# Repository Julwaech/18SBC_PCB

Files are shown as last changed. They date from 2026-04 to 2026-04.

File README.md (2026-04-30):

# 18SBC PCB

18-Series Battery Connector Board — a high-current PCB designed for 18S lithium battery pack integration in heavy-lift UAV systems.

## Overview

The 18SBC is a battery connector board that interfaces 18S smart battery packs (e.g. Tattu 4.0) with the aircraft electrical system.

### Design Goals

- Support 18S smart batteries (Tattu 4.0 compatible)
- Handle 100A continuous / 200A spike current
- Provide galvanically isolated 12V output (GNDE) to the aircraft power distribution board
- Provide non-isolated 5V / 3.3V (GNDI) for onboard logic (ESP32, CAN, diagnostics)
- Active power switching with precharge and emergency shutoff
- Dual CAN bus communication (battery protocol + DroneCAN)
- Wireless connectivity (WiFi / BLE) for diagnostics and configuration
- USB-C interface for debugging, firmware flashing, and development

## Board Overview (Fusion 360 Renders)

> **Note:** These renders are for visualization purposes — the ESP32-S3, MCP2515, and other small ICs are not yet modeled in the CAD. The renders show the physical layout of the major connectors, fuse, and power path components.

### Render 1 — Board Inserted in 18S Tattu Battery

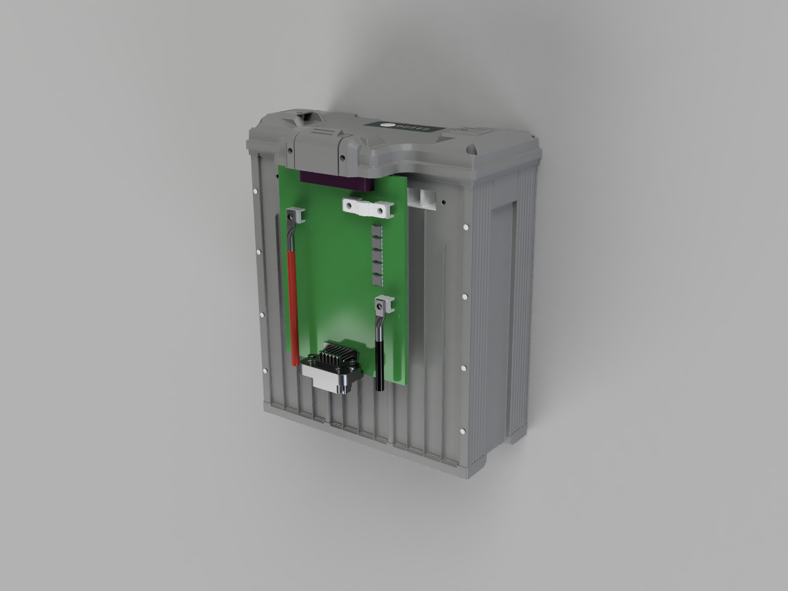
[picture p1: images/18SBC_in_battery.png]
18SBC in Tattu Battery


The board is shown inserted vertically into an 18S Tattu 4.0 smart battery pack to illustrate how the battery connector (purple, top) mates with the battery's interface.

**Visible components (top to bottom):**

| Position | Component | Description |
|---|---|---|
| Top | **AMT0650009DB0000G** screw terminals + **DB128V-5.08-4P-GN-S** signal terminal | Battery interface — power (+ / -) and CAN L/H + interlock signals. Layout: Positive (left) \| Signal (center) \| Negative (right) |
| Upper right | **White ceramic component** (AMXL-250) | 250A main fuse, bolt-mounted on 2x AMT0650009DB0000G screw terminals |
| Below fuse | **MOSFETs** | Power switching (precharge, kill switch, power enable) |
| Below MOSFETs | **Black cable** with ring lug | Negative output to Hobbywing X15 propulsion, connected via AMT0650009DB0000G screw terminal |
| Middle left | **Red cable** with ring lug | Positive output to Hobbywing X15 propulsion, connected via AMT0650009DB0000G screw terminal |
| Bottom | **AT13-12PB-BM03** signal connector | 12-position Amphenol AT series — interfaces with the drone electrical harness (12V, 5V, GND, CAN, signals) |

### Render 2 — Board Front View

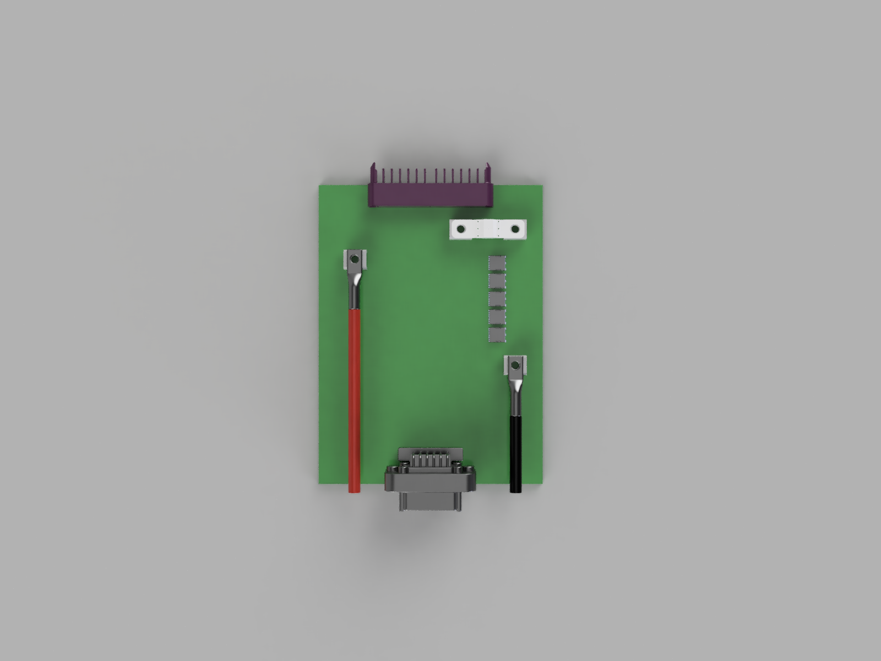
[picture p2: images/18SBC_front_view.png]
18SBC Front View


Frontal view of the PCB showing component placement and general board layout. The power path flows from the battery connector (top) through the fuse and MOSFETs to the propulsion screw terminals (red/black cables). The signal connector exits at the bottom toward the drone harness.

### Signal Flow

```
Battery (18S Tattu 4.0)
        |
        v
+---------------------+
|  Battery Terminals   |  <- Power (+ / -) via AMT0650009DB0000G
|  + Signal Terminal   |  <- CAN L/H + Interlock via DB128V-5.08-4P
+---------------------+
|  AMXL-250 Fuse       |  <- 250A short-circuit protection
+---------------------+
|  MOSFETs             |  <- Precharge / Kill switch / Power enable
+---------------------+
|  Screw Terminals     |  <- Red (+) and Black (-) cables
|  (AMT0650009DB0000G) |     to Hobbywing X15 propulsion
+---------------------+
|                       |
|  HV Bus (54-75.6V)   |
|    |            |     |
|    v            v     |
|  [Buck]    [Push-Pull]|
|  5V/1A     12V/10A   |
|  (GNDI)    (isolated) |
|    |        (GNDE)    |
|    v            |     |
|  [LDO]         |     |
|  3.3V          |     |
|  (GNDI)        |     |
+---------------------+
|  AT Signal Connector |  <- 12V (GNDE), DroneCAN, signals
|  (AT13-12PB-BM03)   |     to aircraft harness
+---------------------+
```

## Specifications

| Parameter | Value |
|---|---|
| Configuration | 18S (18 series cell groups) |
| Max Voltage | 75.6V (4.2V x 18) |
| Nominal Voltage | 64.8V (3.6V x 18) |
| Continuous Current | 100A |
| Spike Current | 200A (short duration) |
| Board Shape | Rectangular |
| EDA Tool | KiCad 10 |
| Board Layers | TBD |

### Current Rating Justification

Based on the motor data (Hobbywing XRotor X15):

| Throttle | Thrust | Current per Motor |
|---|---|---|
| 51% | 27,257 g | 44.7 A |
| 72% | 47,933 g | 101.6 A |
| 100% | 72,647 g | 197.1 A |

The Hover throttle is ~50%. The 100A nominal rating covers normal operations; the 200A spike rating handles full-throttle bursts.

## Connectors and Fuse

### Battery Connector

#### Mating Connector (Battery Side): ACES 59604-0169D-003

This is the connector built into the Tattu 4.0 battery pack. The Prolanv EN60A on the 18SBC mates with this connector.

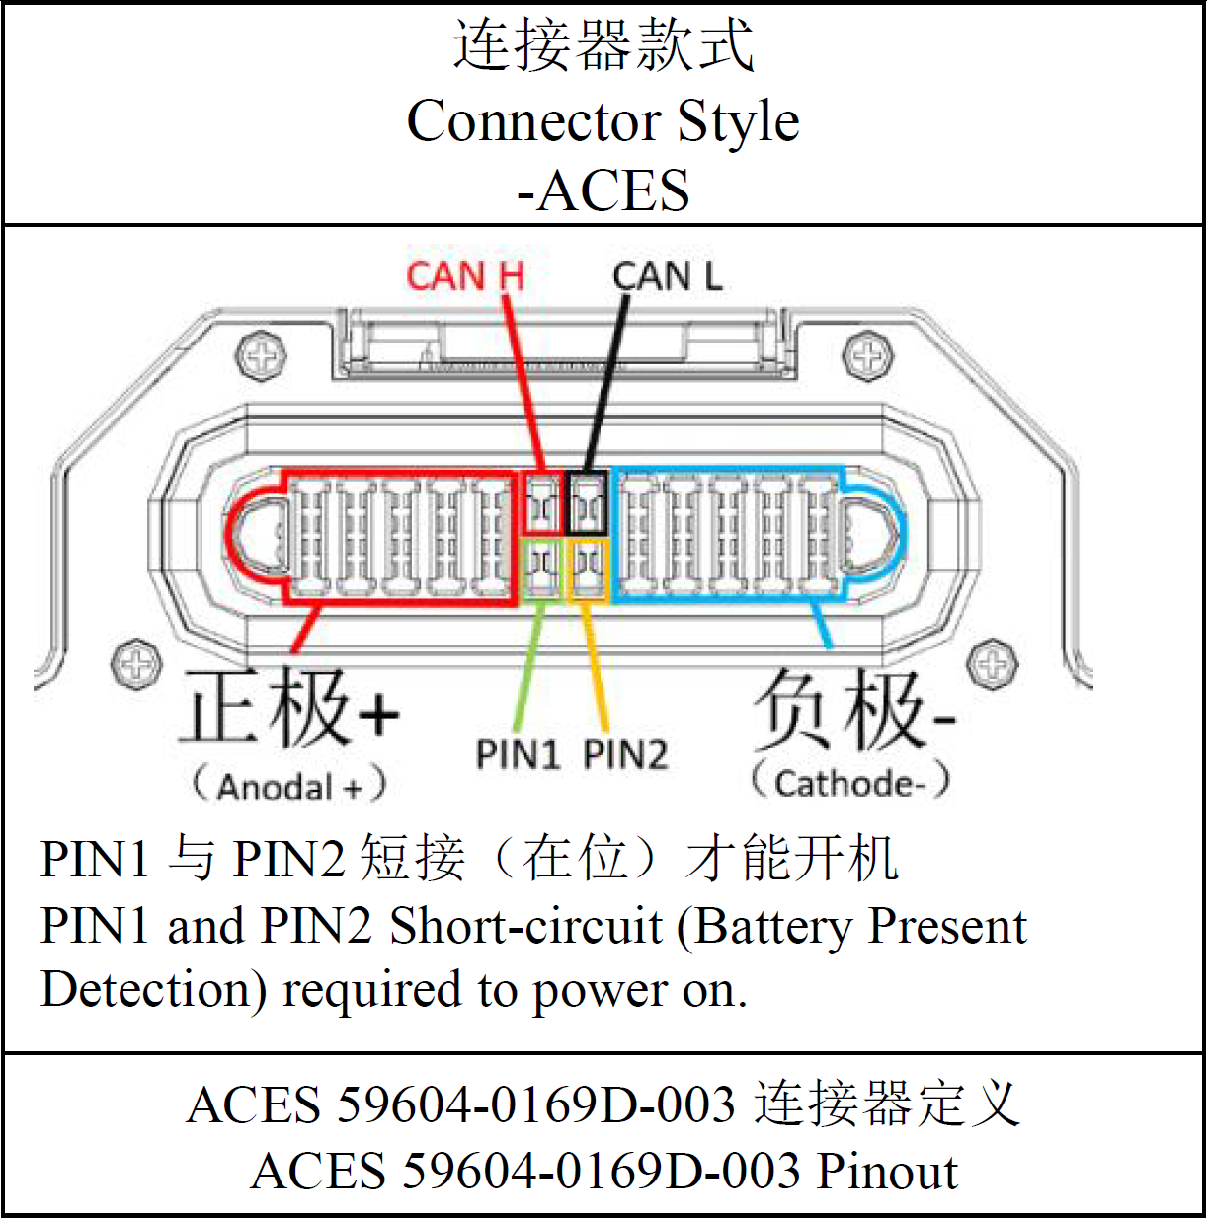
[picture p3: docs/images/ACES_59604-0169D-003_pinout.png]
ACES 59604-0169D-003 Pinout


| Position | Function | Notes |
|---|---|---|
| Left bank (red) | Anodal + (Positive) | Multiple parallel power contacts |
| Right bank (blue) | Cathode - (Negative) | Multiple parallel power contacts |
| Center top | CAN H + CAN L | Battery communication bus |
| PIN1 + PIN2 (center bottom) | Battery Present Detection | Must be shorted (bridged) for the battery to power on |

> **Important:** PIN1 and PIN2 must be short-circuited by the mating connector (Prolanv EN60A) to signal "battery present" — the battery will not power on without this bridge. The 18SBC must include a trace or jumper connecting these two pins on the EN60A side.

#### Board-Side Connectors: AMT0650009DB0000G (Power) + DB128V-5.08-4P-GN-S (Signal)

The original Prolanv EN60A connector was replaced due to mechanical fit issues. The battery interface now uses separate power and signal connectors:

**Power Terminals: [Amphenol Anytek AMT0650009DB0000G](https://www.mouser.com/ProductDetail/Amphenol-Anytek/AMT0650009DB0000G)**

Two screw terminals for positive and negative battery connections, same as used for propulsion output and fuse mounting.

| Parameter | Value |
|---|---|
| Type | Screw Terminal, Power Tap |
| Screw Size | M5 |
| Current Rating | 180A per terminal |
| Mounting | Through-Hole DIP |

**Signal Terminal: [DB128V-5.08-4P-GN-S](https://www.lcsc.com/product-detail/C2915641.html) (4-pin screw terminal block)**

| Parameter | Value |
|---|---|
| Type | 4-position screw terminal block |
| Pitch | 5.08mm |
| Pins | 4 (CAN H, CAN L, Interlock Pin1, Interlock Pin2) |
| LCSC | C2915641 |

**PCB Layout (top of board, left to right):**
- Positive terminal (AMT0650009DB0000G) — left
- Signal terminal (DB128V-5.08-4P-GN-S) — center
- Negative terminal (AMT0650009DB0000G) — right

> **Hardware Interlock:** Pin1 and Pin2 on the signal terminal must be bridged on the PCB. This signals "battery present" to the battery pack — the battery will not power on without this connection.

### Propulsion Screw Terminals

**Selected: [Amphenol Anytek AMT0650009DB0000G](https://www.mouser.com/ProductDetail/Amphenol-Anytek/AMT0650009DB0000G)**

These are the high-current screw terminals where cables to the Hobbywing X15 propulsion system are connected (+ and -).

| Parameter | Value |
|---|---|
| Type | Screw Terminal, Power Tap |
| Screw Size | M5 |
| Pins | 6 |
| Current Rating | 180A |
| Mounting | Through-Hole DIP |
| Contact Material | Brass + Steel Nut (matte tin plated) |
| Torque | 18 lbf·in |

Two sets of AMT0650009DB0000G screw terminals are used on the board: one pair for the propulsion output (+ / -), and another pair for mounting the main fuse (see below).

### Signal Connector (Drone Interface)

**Selected: [Amphenol AT13-12PB-BM03](https://www.amphenol-sine.com/AT13-12PB-BM03-12-Position-Right-Angle-Flange-Mount-PCB-Receptacle-Black-Tin-Plated-Contacts-Included-Keyed-B-Comparable-to-PN-DT13-12P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) (or similar AT series)**

This connector interfaces the 18SBC with the rest of the drone's electrical system (signal lines, regulated power outputs, CAN buses).

| Parameter | Value |
|---|---|
| Series | Amphenol AT (automotive-grade) |
| Type | Right-Angle Flange Mount PCB Receptacle |
| Positions | 12 |
| Keying | B |
| Contact Plating | Tin |
| Mating Connector | AT series cable plug (wire-to-board) |

The AT series is an automotive/industrial-grade connector family designed for harsh environments — vibration-resistant, sealed, and rated for high mating cycles. The 12 positions carry the isolated 12V output (GNDE), CAN bus lines, and control signals.

### USB-C Connector (Debug / Programming)

A USB-C connector is provided for firmware flashing, serial debugging, and development. It connects to the ESP32-S3's native USB interface (GPIO19 = D-, GPIO20 = D+).

| Parameter | Value |
|---|---|
| Type | USB-C receptacle |
| Interface | USB 2.0 (native ESP32-S3 USB) |
| Purpose | Firmware flashing, serial monitor, debugging |
| Power | Not used for board power (debug only) |
### Main Fuse (Short-Circuit Protection)

**Selected: [Eaton AMXL-250](https://www.eaton.com/content/dam/eaton/products/electronic-components/resources/data-sheet/eaton-amx-amxl-automotive-bolt-in-fuse-data-sheet-elx1218-en.pdf)**

The main fuse sits between the battery connector and the power output stage, protecting against short circuits. It is mounted on two AMT0650009DB0000G screw terminals (bolt-in design).

| Parameter | Value |
|---|---|
| Type | Automotive bolt-in fuse |
| Current Rating | 250A |
| Voltage Rating | 125 Vdc |
| Body | Ceramic |
| Mounting | Bolt-in (M5 terminals) on 2x AMT0650009DB0000G |

The 250A fuse rating provides short-circuit protection while allowing the full 200A spike current without nuisance blowing. The ceramic body handles the thermal demands of high-current interruption.

## MCU and Communication

### MCU: ESP32-S3-WROOM-1-N16R8

The ESP32-S3-WROOM-1-N16R8 module is a compact RISC-V based microcontroller with integrated wireless connectivity. It includes a PCB antenna — no external antenna components are required. A keepout zone must be maintained around the antenna area on the PCB layout (no copper / ground plane underneath).

| Parameter | Value |
|---|---|
| Core | Dual-core Xtensa LX7, 240 MHz |
| Flash | 16 MB (external quad SPI) |
| SRAM | 512 KB |
| WiFi | 802.11 b/g/n (2.4 GHz) |
| Bluetooth | BLE 5.0 |
| GPIOs | 45 |
| SPI | 3x (1 used for dual MCP2515) |
| ADC | 20 channels, 12-bit |
| Operating Voltage | 3.0 – 3.6V |
| Deep Sleep Current | 7 uA |
| Antenna | Integrated PCB antenna |

### Dual CAN Bus (2x MCP2515 + Transceiver)

Two independent CAN networks using external MCP2515 controllers on a shared SPI bus. This provides identical timing behavior on both buses and clean separation of the battery-side and drone-side CAN domains.

| CAN Bus | Purpose | Controller | Transceiver |
|---|---|---|---|
| CAN 1 — Battery | Battery protocol (smart battery communication) | MCP2515 (SPI, CS1) | SN65HVD230 (3.3V) |
| CAN 2 — Drone | DroneCAN (UAVCAN v0) interface to aircraft | MCP2515 (SPI, CS2) | SN65HVD230 (3.3V) |

Each MCP2515 requires an 8 MHz crystal + 2x 22pF load capacitors. 120 Ohm termination resistors are optional (directly connected or selectable via solder jumper depending on bus topology).

The board converts between the battery protocol (CAN 1) and DroneCAN (CAN 2) using [libcanard](https://github.com/dronecan/libcanard).

### GPIO Allocation

| Function | GPIOs | Notes |
|---|---|---|
| SPI Bus (shared) — SCK, MOSI, MISO | 3 | Directly routed to both MCP2515 |
| MCP2515 #1 — CS1, INT1 | 2 | CAN 1 (Battery) |
| MCP2515 #2 — CS2, INT2 | 2 | CAN 2 (Drone) |
| Temperature Sensors | 2 | 1-Wire (e.g. DS18B20) or analog NTC via ADC |
| Circuit Switching | 4 | MOSFET gate drive (e.g. precharge, kill switch, power enable) |
| USB (D+ / D-) | 2 | Native USB for debugging/flashing |
| **Total Used** | **15** | |
| **Remaining / Reserve** | **30** | Available for future expansion |

Pin count provides comfortable headroom for all current functions with 9 GPIOs in reserve.

## Functional Requirements

### Power Path
- **High-side MOSFET switching** — N-channel MOSFETs with charge pump gate drive
- **Precharge circuit** — soft-start via resistor + relay/MOSFET to limit inrush current
- **Emergency kill switch** — hardware-level kill input, independent of MCU
- **Main fuse** — Eaton AMXL-250 (250A) bolt-in fuse for short-circuit protection

### Voltage Regulation

The power supply architecture uses two independent stages with full galvanic isolation between internal onboard logic (GNDI) and external drone systems (GNDE).

#### Internal Supply (GNDI — non-isolated)

Provides power for onboard logic (ESP32, MCP2515, CAN transceivers, gate drivers, sensors).

| Stage | Topology | IC | Input | Output | Notes |
|---|---|---|---|---|---|
| 5V Rail | Sync Buck | e.g. MP9487 or similar (100V+, integrated FETs, ≥1A) | 54–75.6V (HV Bus) | 5V / 1A | Main internal rail |
| 3.3V Rail | LDO | e.g. AMS1117-3.3 or similar | 5V | 3.3V | ESP32, MCP2515, CAN transceivers |

#### External Supply (GNDE — galvanically isolated)

Provides 12V to the aircraft power distribution board. Full galvanic isolation ensures no ground loops between the 6 battery packs in the aircraft, and prevents EMI/noise from the propulsion system reaching sensitive avionics.

| Stage | Topology | IC | Input | Output | Notes |
|---|---|---|---|---|---|
| Isolated 12V | Push-Pull | e.g. TI LM5030 or similar push-pull controller | 54–75.6V (HV Bus) | 12V / 10A (isolated) | 1:N transformer, GNDI ↔ GNDE fully isolated |

> **Isolation rationale:** The aircraft uses 6 independent battery packs, each with its own 18SBC. All 6 isolated 12V outputs are combined on a central power distribution board. Without isolation, all battery GNDs would be connected through the shared 12V/5V rails — creating ground loops and coupling propulsion noise into avionics. Galvanic isolation on each 18SBC prevents this.

### Monitoring and Communication
- **Dual CAN bus** — see [MCU and Communication](#mcu-and-communication) section above
- **Temperature sensors** — 2 pins reserved for monitoring battery connector and MOSFET hotspots (1-Wire or NTC/ADC)
- **WiFi / BLE** — integrated in ESP32-S3 for wireless diagnostics, configuration, and telemetry

### Protection
- **Short circuit protection** — Eaton AMXL-250 bolt-in fuse (250A, 125Vdc) mounted on dedicated screw terminals

## Repository Structure

```
18SBC_PCB/
├── README.md
├── kicad/              # KiCad 10 project files
│   ├── 18SBC.kicad_pro
│   ├── 18SBC.kicad_sch
│   └── 18SBC.kicad_pcb
├── docs/               # Documentation and datasheets
├── manufacturing/      # Gerber files and BOM
├── firmware/           # ESP32-S3 firmware (ESP-IDF / Arduino)
└── images/             # Board renders and photos
```

## Deliverables

1. **Schematic** — complete KiCad schematic with all subsystems
2. **PCB Layout** — rectangular board, routed for high current, antenna keepout zone respected
3. **BOM** — full bill of materials with supplier links
4. **Gerber files** — manufacturing-ready output for JLCPCB
5. **Documentation** — kicad files with component/footprint libraries in a zip folder.

## Getting Started

1. Install [KiCad 10](https://www.kicad.org/)
2. Clone this repository
3. Open `kicad/18SBC.kicad_pro`

## Reference Links

- [ESP32-S3-WROOM-1-N16R8 Datasheet](https://www.espressif.com/sites/default/files/documentation/esp32-s3-wroom-1-n16r8_datasheet_en.pdf) — MCU module
- [MCP2515 Datasheet](https://ww1.microchip.com/downloads/en/DeviceDoc/MCP2515-Stand-Alone-CAN-Controller-with-SPI-20001801J.pdf) — CAN controller
- [SN65HVD230 Datasheet](https://www.ti.com/lit/ds/symlink/sn65hvd230.pdf) — 3.3V CAN transceiver
- [AMT0650009DB0000G (Mouser)](https://www.mouser.com/ProductDetail/Amphenol-Anytek/AMT0650009DB0000G) — 180A screw terminal (propulsion + fuse mount)
- [AT13-12PB-BM03 (Amphenol)](https://www.amphenol-sine.com/AT13-12PB-BM03-12-Position-Right-Angle-Flange-Mount-PCB-Receptacle-Black-Tin-Plated-Contacts-Included-Keyed-B-Comparable-to-PN-DT13-12P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) — 12-pos signal connector
- [Eaton AMXL-250 Datasheet (PDF)](https://www.eaton.com/content/dam/eaton/products/electronic-components/resources/data-sheet/eaton-amx-amxl-automotive-bolt-in-fuse-data-sheet-elx1218-en.pdf) — 250A bolt-in fuse
- [DroneCAN](https://dronecan.github.io/) — CAN protocol for UAVs
- [libcanard](https://github.com/dronecan/libcanard) — lightweight DroneCAN implementation in C
- [DB128V-5.08-4P-GN-S (LCSC)](https://www.lcsc.com/product-detail/C2915641.html) — 4-pin screw terminal block (battery signal connector)
- [ESP32-S3-WROOM-1-N16R8 (LCSC)](https://www.lcsc.com/product-detail/C2913202.html) — MCU module (LCSC sourcing)

## License

TBD

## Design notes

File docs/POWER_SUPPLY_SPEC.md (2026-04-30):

# Power Supply Specification

## Overview

The 18SBC includes two independent step-down voltage regulators to provide power to external systems (flight controller, peripherals, sensors). These regulators are part of the **External GND Domain** and are galvanically separated from the internal board logic.

## Input

| Parameter | Value |
|---|---|
| Source | 18S HV Battery Bus |
| Voltage Range | 54.0V - 75.6V (3.0V - 4.2V per cell) |
| Component Rating | 100V DC |
| TVS Protection | 85V |

## Regulators

### Regulator 1 - 5V Rail

| Parameter | Value |
|---|---|
| Output Voltage | 5V (+-1.5%) |
| Continuous Current | 3-5A |
| Topology | Synchronous Buck |
| Efficiency | 90-96% typical |
| Output Ripple | <=35mV at full load |
| Protections | Overcurrent (self-recovery), thermal cutoff (150C), short-circuit tolerant |

### Regulator 2 - 12V Rail

| Parameter | Value |
|---|---|
| Output Voltage | 12V (+-1.5%) |
| Continuous Current | 3-5A |
| Topology | Synchronous Buck |
| Efficiency | 90-96% typical |
| Output Ripple | <=60mV at full load |
| Protections | Overcurrent (self-recovery), thermal cutoff (150C), short-circuit tolerant |

## Ground Domain Architecture

The 18SBC has two electrically separated ground domains:

### Internal GND (GNDI)
- ESP32-S3 MCU
- BMS logic
- MOSFET gate drivers
- Cell voltage sensing
- All internal signal processing

### External GND (GNDE)
- 5V and 12V regulator outputs
- Kill signal input (see [Kill Switch Spec](KILL_SWITCH_SPEC.md))
- All external connectors / interfaces

### Isolation Boundary

Signals crossing from External to Internal domain (or vice versa) **must be isolated**. Acceptable methods:
- Optocouplers
- Isolated gate drivers
- Isolated DC/DC converters

> **Rule:** DCDC regulator outputs may only be used internally if the signal path includes galvanic isolation before reaching the Internal GND domain.

## Battery Voltage Sensing

| Parameter | Value |
|---|---|
| Voltage Divider | 1k : 25k (input : ground) |
| Output | 0-2.91V for 0-75.6V input |
| Interface | 3.3V ADC compatible |
| Domain | Internal GND |

## Internal Power Supply

> **TBD** - The power source for the internal domain (ESP32-S3, BMS logic, etc.) is yet to be defined. Options under consideration include a dedicated isolated DC/DC converter from the HV bus or an isolated tap from one of the external regulators.

## Integration Notes

- The **Kill Switch** ([spec](KILL_SWITCH_SPEC.md)) operates on the External GND domain (12V rail). The kill signal crosses into the Internal domain via an optocoupler to reach the hardware AND-gate that controls the MOSFET enable line.
- External connectors must clearly indicate which ground domain they reference (GNDE).

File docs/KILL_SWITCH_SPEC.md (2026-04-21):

# 18SBC Emergency Kill Switch Specification

## Overview
The 18SBC receives a **12V emergency kill signal** from the Flight Controller (FC) via a dedicated cable. This signal must be hardware-debounced and capable of overriding the ESP32 MOSFET control to cut battery power.

## Signal Input
- **Voltage:** 12V (amplified from FC GPIO on a separate board)
- **Active State:** HIGH = Kill requested
- **Connector:** TBD (dedicated pin on signal connector)

## Hardware Debounce (1s minimum)
To prevent false cutoffs during flight (which would cause a crash), the kill signal must be stable for **>=1 second** before triggering.

### Implementation: RC Filter + Schmitt-Trigger
- **R = 150k ohm, C = 10uF** -> tau = 1.5s
- **Schmitt-Trigger** (e.g. 74LVC1G17, 3.3V logic):
  - Voltage divider before Schmitt-Trigger to scale 12V -> 3.3V range
  - Triggers at ~70% of input -> effective delay approx 1.05s
- Short spikes and EMI noise are fully absorbed by the RC filter

**Output:** KILL_CONFIRMED -- HIGH only after >=1s stable kill signal

## MOSFET Control Logic (Hardware AND-Gate)
The MOSFETs are controlled by a **hardware AND-gate** (e.g. 74LVC1G08) that combines the ESP32 enable signal with the inverted kill signal:

```
MOSFET_ENABLE = ESP32_ENABLE AND (NOT KILL_CONFIRMED)
```

### Truth Table
| ESP32_ENABLE | KILL_CONFIRMED | MOSFETs | State |
|---|---|---|---|
| LOW | LOW | **OFF** | Boot / Error |
| HIGH | LOW | **ON**  | Normal Operation |
| HIGH | HIGH | **OFF** | Emergency Kill |
| LOW | HIGH | **OFF** | Kill + No Enable |

### Key Properties
- **Default state is OFF** -- safe during boot, reset, or ESP32 failure
- **Hardware override** -- ESP32 cannot block or bypass the kill signal
- **ESP32 enable is active-high** -- must be explicitly driven HIGH for MOSFETs to turn on
- The AND-gate operates purely in hardware, independent of any firmware

## Component Summary
| Component | Part (Example) | Function |
|---|---|---|
| R (debounce) | 150k ohm | RC time constant with C |
| C (debounce) | 10uF | RC time constant with R |
| Voltage divider | Resistors TBD | Scale 12V kill signal to 3.3V |
| Schmitt-Trigger | 74LVC1G17 | Clean digital output from RC |
| Inverter | 74LVC1G04 | Invert KILL_CONFIRMED |
| AND-Gate | 74LVC1G08 | Combine ESP32_ENABLE + NOT KILL |

## Design Priorities
1. **No false cutoff during flight** -- 1s debounce + noise-immune 12V bus
2. **Guaranteed kill when intended** -- pure hardware path, no firmware dependency
3. **Safe default state** -- MOSFETs OFF unless explicitly enabled

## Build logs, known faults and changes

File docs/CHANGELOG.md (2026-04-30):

# Changelog

## 2025-04-29 — Design Revision

### Changed
- **MCU:** ESP32-C3-MINI-1 replaced with **ESP32-S3-WROOM-1-N16R8** (LCSC C2913202)
  - Reason: ESP32-C3 has insufficient GPIOs for all required functions
  - ESP32-S3 provides 45 GPIOs, dual-core Xtensa LX7 @ 240 MHz, 16MB flash, 512KB SRAM
  - Native USB support (no external USB-UART bridge needed)
- **Battery connector:** Prolanv EN60A removed due to mechanical fit issues
  - **Power:** Now uses **AMT0650009DB0000G** screw terminals (same as propulsion output)
  - **Signal/CAN:** New **DB128V-5.08-4P-GN-S** 4-pin screw terminal block (LCSC C2915641)
  - PCB layout (top of board): Positive (left) | Signal (center) | Negative (right)

### Added
- **USB-C connector** for debugging, firmware flashing, and serial monitoring
  - Connects to ESP32-S3 native USB (GPIO19 D-, GPIO20 D+)
- **Hardware interlock documentation:** Pin1 and Pin2 on the battery signal connector must be bridged on the PCB to activate the battery

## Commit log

2026-04-15 docs: comprehensive README with specs, connector, and requirements
2026-04-20 docs: update MCU to ESP32-C3-MINI-1 with dual MCP2515 CAN
2026-04-20 docs: add connectors (AMT0650009DB0000G, AT13-12PB-BM03) and main fuse (AMXL-250) to README
2026-04-20 docs: add Board Overview section with Fusion 360 render descriptions and signal flow diagram
2026-04-20 Add render: 18SBC PCB in Tattu battery
2026-04-20 Add render: 18SBC PCB front view
2026-04-20 Add first kicad draft
    [18SBC.kicad_pcb, 18SBC.kicad_sch]
2026-04-21 docs: add emergency kill switch specification
2026-04-21 docs: add power supply specification
2026-04-21 docs: rewrite power supply spec (5V+12V external, GND domains, isolation)
2026-04-21 docs: update power supply architecture — isolated 12V (GNDE) + non-isolated 5V/3.3V (GNDI)
2026-04-21 fix: remove incorrect BMS references — 18SBC is a connector board, not a BMS
2026-04-21 docs: add ACES 59604-0169D-003 connector pinout diagram
2026-04-21 docs: add ACES 59604-0169D-003 battery-side connector pinout and PIN1/PIN2 detection info
2026-04-30 Update MCU to ESP32-S3-WROOM-1-N16R8, add USB-C, replace battery connector
2026-04-30 Update ESP32 references to ESP32-S3
